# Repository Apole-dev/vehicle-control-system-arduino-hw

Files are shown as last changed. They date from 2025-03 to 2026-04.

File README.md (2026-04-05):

<div align="center">

# Vehicle Control System Hardware Design





</div>

This repository contains the hardware design (schematic and PCB) files and test firmware for the project. The system is based on the **ATmega328P** microcontroller, designed to read, process, and transmit vehicle data over long distances.

## Hardware Features & Integrations

The design is a custom printed circuit board (PCB) operating at a 5V logic level, consolidating various communication modules onto a single board.

* **Power Management:** The system's 5V requirement is supplied by an **LM2596** step-down (buck) regulator module powered via a standard DC Jack.
* **Microcontroller:** DIP-28 package **ATmega328P** utilizing an external crystal oscillator circuit.
* **In-Vehicle Communication (CAN Bus):** Access to the vehicle's network via an **MCP2515** CAN controller module connected through the SPI interface (J3 socket).
* **Telemetry (LoRa):** **LoRa** module integration with a dedicated UART socket (M0, M1, RX, TX, AUX) for long-range wireless data transmission.
* **Location Tracking (GPS):** A GPS module connected to a secondary hardware/software UART line (J5 socket) for speed, location, and timing (PPS) data.
* **Status Indicators:** 6 dedicated debug LEDs connected to pins PC0-PC5 to easily visualize system status, communication packets, or error codes.

## Pinout Summary
* `PC0 - PC5` : Status LEDs (D1 - D6)
* `PB3, PB4, PB5` : SPI Line (MCP2515 CAN Module)
* `PD0, PD1, PD2, PD3, PD4` : LoRa UART and Control (RX, TX, M0, M1, AUX)
* `PD6, PD7` : GPS UART and PPS signals

---

## Schematic

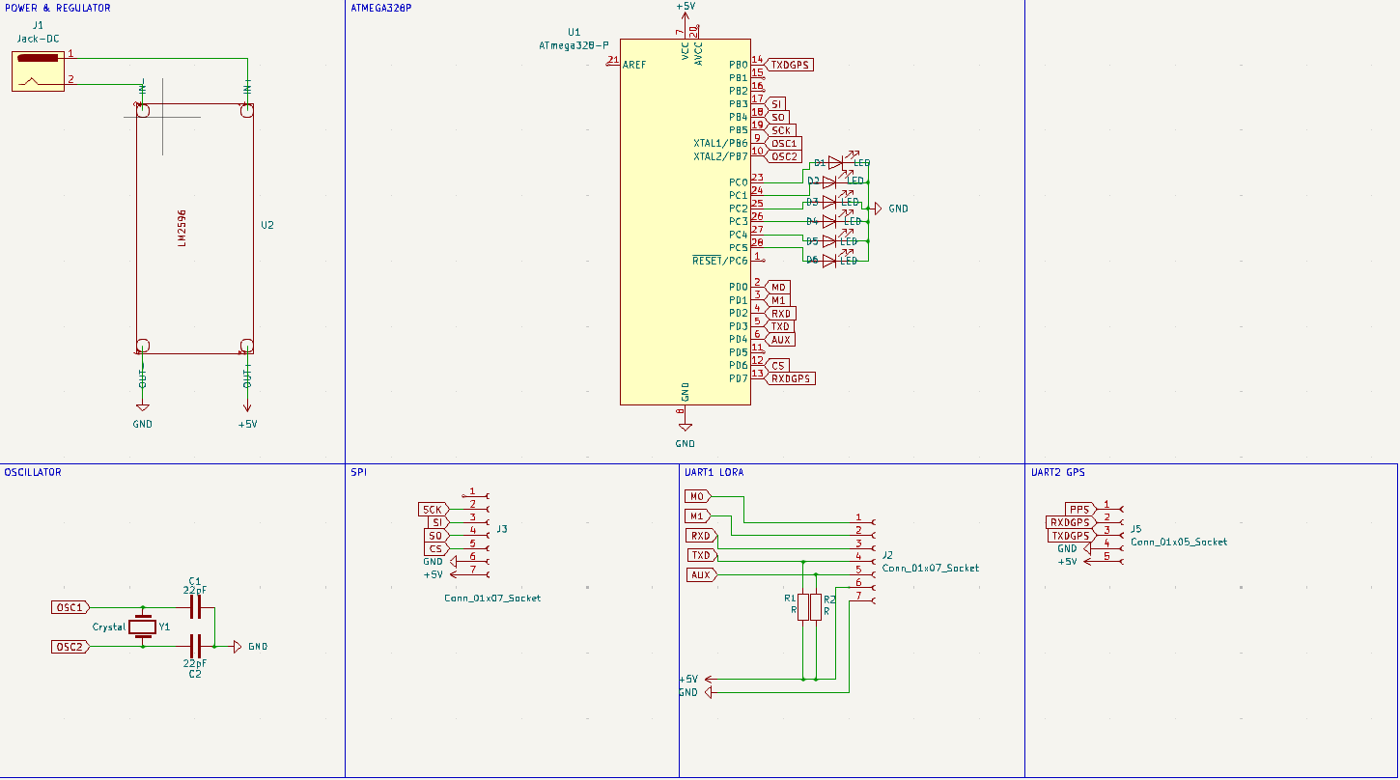
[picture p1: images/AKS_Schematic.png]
AKS Şematik


---

## PCB

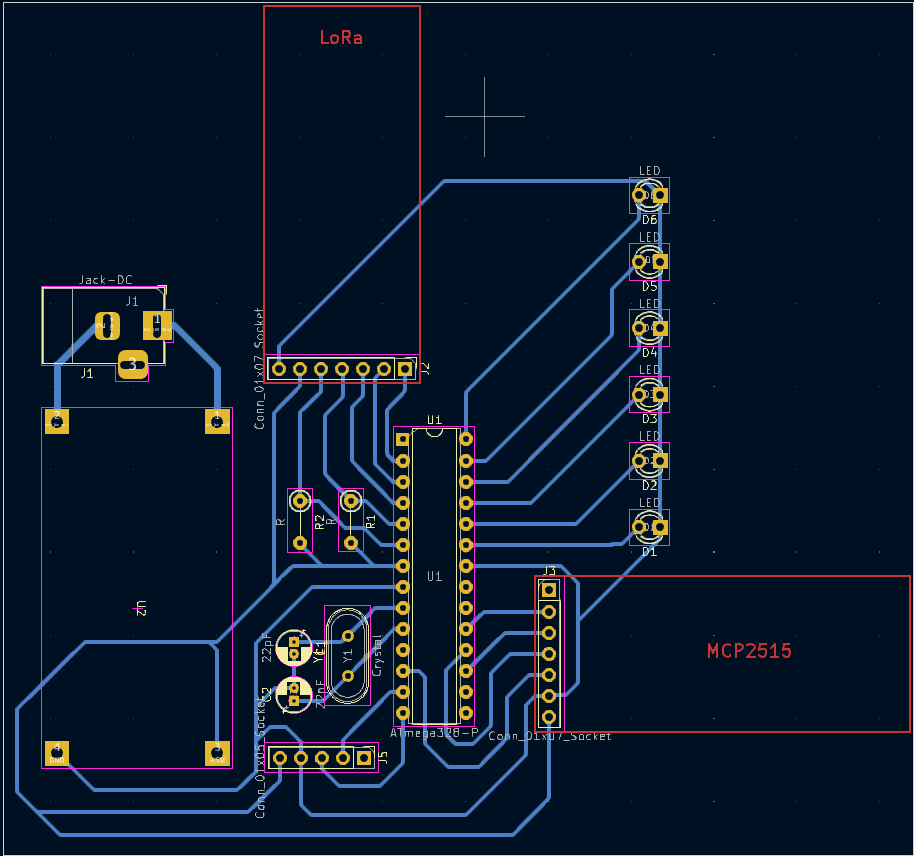
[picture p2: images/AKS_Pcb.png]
AKS PCB


---
## Contributors
<a href="https://github.com/ravzagulsahin">
  Contributor 1
</a>
<a href="https://github.com/Aytunctr">
  Contributor 2
</a>

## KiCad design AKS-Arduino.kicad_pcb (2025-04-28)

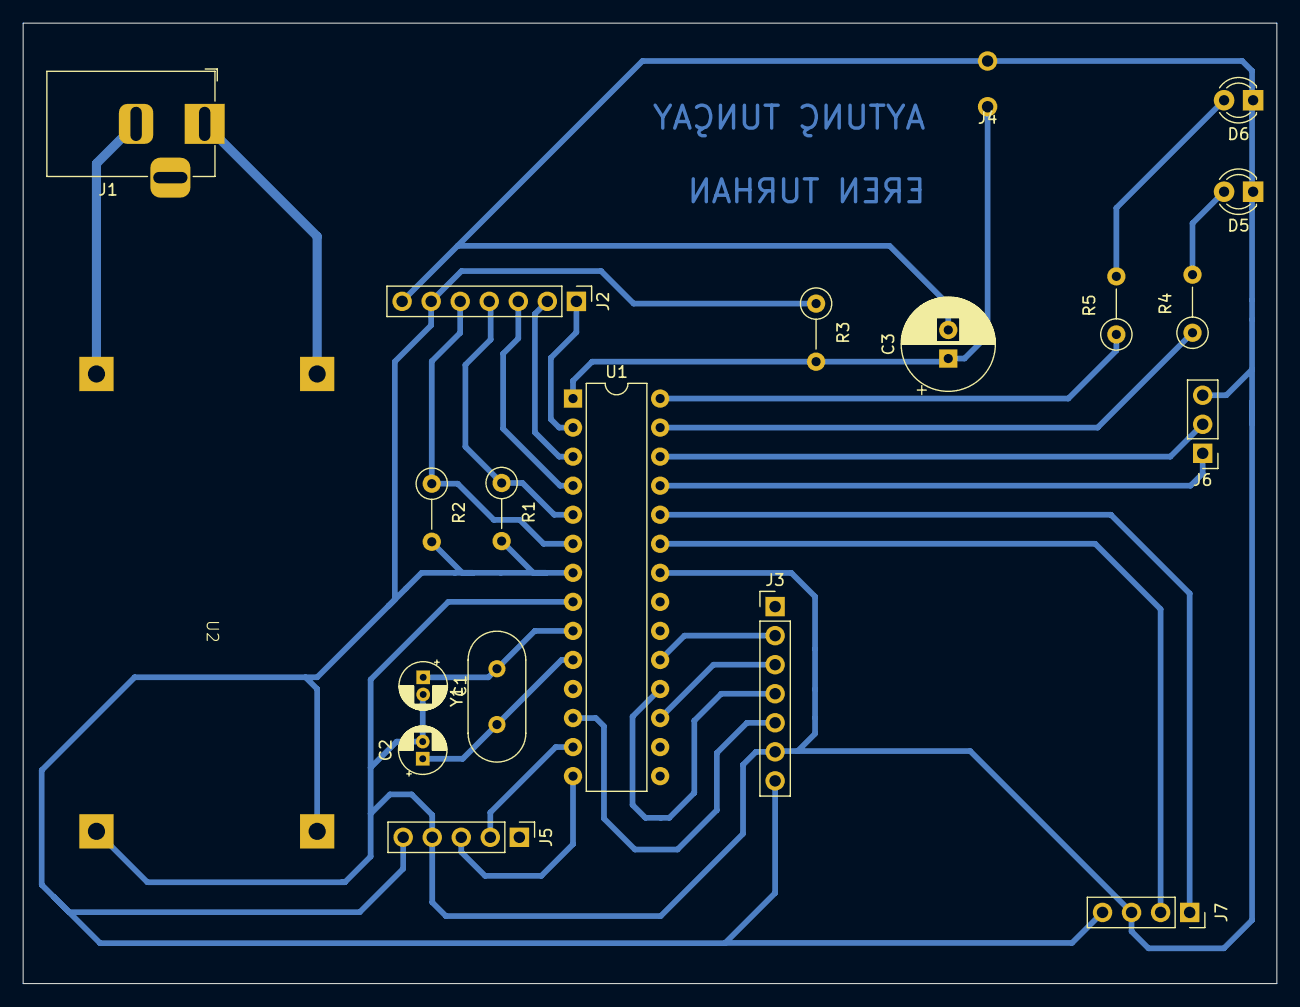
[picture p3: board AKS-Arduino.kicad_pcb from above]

Board: 2 copper layers, 109.6 x 84.0 mm, 20 parts (0 on the bottom side), 26 nets.

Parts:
C1, C2: 22pF; CP_Radial_D4.0mm_P1.50mm
C3: C_Polarized_US; CP_Radial_D8.0mm_P2.50mm
D5, D6: LED; LED_D3.0mm
J1: Jack-DC; BarrelJack_Horizontal
J2, J3: Conn_01x07_Socket; PinHeader_1x07_P2.54mm_Vertical
J4: Conn_01x02_Socket; PinSocket_1x02_P2.54mm_Vertical
J5: Conn_01x05_Socket; PinHeader_1x05_P2.54mm_Vertical
J6: Conn_01x03_Socket; PinHeader_1x03_P2.54mm_Vertical
J7: Conn_01x04_Socket; PinSocket_1x04_P2.54mm_Vertical
R1, R2, R3, R4, R5: R; R_Axial_DIN0207_L6.3mm_D2.5mm_P5.08mm_Vertical
U1: ATmega328-P; DIP-28_W7.62mm
U2: regulator
Y1: Crystal; Crystal_HC49-4H_Vertical

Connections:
+5V: J2.6, J3.7, J5.5, J7.4, R1.2, R2.2, R3.1, U1.7 (VCC), U2.3 (OUT+)
AUX: J2.5, R2.1, U1.6 (PD4)
CS: J3.5, U1.12 (PD6)
GND: C1.2, C2.2, C3.2, D5.1 (K), D6.1 (K), J2.7, J3.6, J4.2, J5.4, J6.3, J7.3, U1.8 (GND), U1.22 (GND), U2.4 (OUT-)
M0: J2.1, U1.2 (PD0)
M1: J2.2, U1.3 (PD1)
unnamed: D5.2 (A), R4.2
unnamed: D6.2 (A), R5.2
unnamed: R4.1, U1.27 (PC4)
unnamed: R5.1, U1.28 (PC5)
unnamed: J1.1, U2.1 (IN+)
unnamed: J1.2, U2.2 (IN-)
Nextion RX: J7.1, U1.24 (PC1)
Nextion TX: J7.2, U1.23 (PC0)
OSC1: C1.1, U1.9 (XTAL1/PB6), Y1.2
OSC2: C2.1, U1.10 (XTAL2/PB7), Y1.1
RESET: C3.1, J4.1, R3.2, U1.1 (~RESET/PC6)
RXD: J2.3, U1.4 (PD2)
RXDGPS: J5.2, U1.13 (PD7)
SCK: J3.2, U1.19 (PB5)
SI: J3.3, U1.17 (PB3)
SO: J3.4, U1.18 (PB4)
Serial RX: J6.1, U1.25 (PC2)
Serial TX: J6.2, U1.26 (PC3)
TXD: J2.4, R1.1, U1.5 (PD3)
TXDGPS: J5.3, U1.14 (PB0)

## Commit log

2025-03-27 Modules added
    [AKS-Arduino.kicad_pcb, AKS-Arduino.kicad_sch]
2025-03-28 Images added
    [AKS-Arduino.kicad_pcb]
2025-04-28 Version 1 Last Update
    [AKS-Arduino.kicad_pcb]
